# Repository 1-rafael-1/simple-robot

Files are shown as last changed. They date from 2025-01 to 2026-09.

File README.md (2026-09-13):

# simple-robot

A not-too-simple tracked robot with autonomous navigation and sensor-driven obstacle avoidance, written in Rust with Embassy. v2 reached the limits of its hardware platform; development continues in the follow-up [explorer-robot](https://github.com/1-rafael-1/explorer-robot) repository.

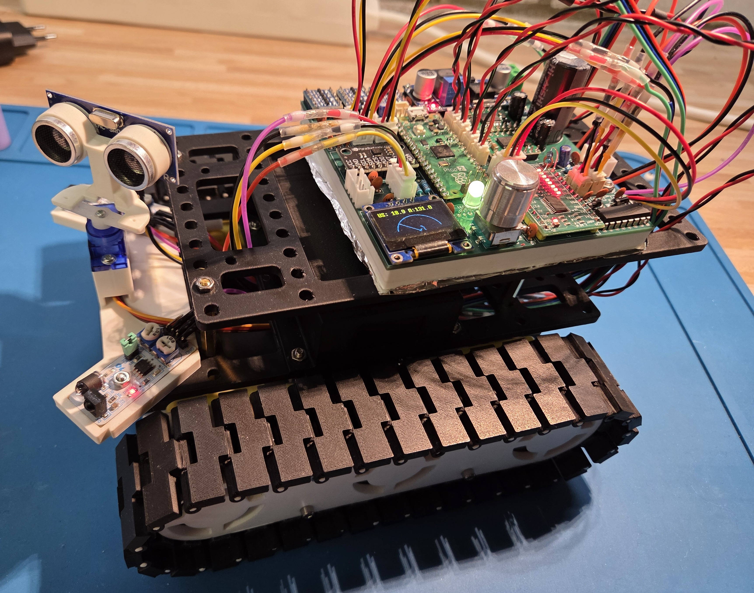
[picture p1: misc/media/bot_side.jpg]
Robot Side View

*Side view showing the robot's profile — the v2 iteration.*

## Project History

This started out as a hobby project for my 10-year-old son, who wanted me to build a robot for him. The thing started as a rather simple machine (v1) and then I got a little carried away. Check out the v1-robot navigating autonomously, download the demo video here: [Autonomous Operation](misc/media/autonomous-mode.mp4).

> Note: The initial version of this robot is preserved in the [`v1` tag](../../tree/v1). That version represents a simple but functional obstacle-avoiding robot using basic components. The v2 iteration described here is tagged [`v2`](../../tree/v2) and is now mothballed.

In v1, the robot could move autonomously by avoiding obstacles in a very simple way. That meant driving straight until an obstacle is detected, back up a little and then make a random turn. It was fun to watch and my son was happy with it.

v2 set out to be much more capable. The plan was to add spatial awareness through an IMU and a sweeping ultrasonic sensor, build more sophisticated autonomous navigation modes, and eventually integrate an AI camera module for follow-me and object-finding. Some of that worked out; some of it ran into hardware limits that couldn't be solved on this platform.

People have pointed out to me various things. The gist is that there are of course ready-made chassis solutions, ready-made RTOS for robotics and even probably complete systems available and that I am setting out to solve things that can be solved with much less effort by using existing things in code as well as hardware. This is all true and I do not dispute it. My motivation is different, though: I am not truly that much interested in having the actual robot, I have no use case at all for it, in fact. I just truly enjoy the process of building, figuring out how to do things, learning a ton of new stuff and it passes my rare spare time in a rewarding way.

## What v2 Achieved

The v2 firmware is a fully integrated platform built on Embassy async with a task-oriented architecture. A central orchestrator runs an event loop, dispatching sensor events to behavior handlers and UI updates. The drive subsystem uses a single-producer command queue with intents for distance drives, in-place rotations, and brake/coast settling — all with IMU-corrected feedback and ramp-down near targets. Mode-agnostic obstacle detection triggers emergency braking across all modes.

The robot carries a custom 4-layer PCB designed in KiCad, hand-soldered, with an RP2350 at 150 MHz. It drives four TT motors through two TB6612FNG motor drivers, reads four hall-effect encoders, and runs an ICM-20948 9-axis IMU with on-chip DMP sensor fusion. An HC-SR04 ultrasonic sensor on a servo performs 0–160° sweeps with a 30° cone correction algorithm, feeding a shared sweep buffer used by both the OLED's radar visualization and the autonomous navigation modes. Two front-facing IR sensors provide close-range collision detection, and a PCA9555 I2C port expander handles motor direction/standby pins and additional inputs. An RGB LED indicates battery state and obstacle alerts.

The UI is driven by an EC11 rotary encoder with push button and an SSD1306 OLED display. A menu system exposes hardware tests (motors, encoders, IMU, ultrasonic sweep, drive accuracy), calibration routines (motor speed, IMU, distance factor), and autonomous mode selection. Calibration data persists to flash storage.

Two autonomous modes are implemented:
- **Coast-and-avoid** — drives forward until an obstacle is detected, backs up, and turns a random angle. Simple but reliable.
- **Attempt straight line** — the user sets a target distance (100–1000 cm); the robot sweeps the ultrasonic sensor, performs gap analysis with drift correction, and navigates leg-by-leg toward the goal while avoiding obstacles.

Three side-quest crates were published along the way: [`hcsr04_async`](https://crates.io/crates/hcsr04_async) (async HC-SR04 driver), [`moving_median`](https://crates.io/crates/moving_median) (moving median filter), and [`icm20948-rs`](https://crates.io/crates/icm20948-rs) (ICM-20948 driver with DMP support).

## Why v2 Ends Here

The robot works, but it cannot reach the spatial awareness and navigation precision the original vision demanded. Several hard limits converge:

**Spatial awareness is the primary bottleneck.** The HC-SR04 ultrasonic sensor, even with servo sweeping and cone correction, is fundamentally imprecise. Its 30° detection cone could have been overcome algorithmically, but it produces false readings far too easily — a carpet, a floor tile seam, or a slightly textured surface registers as an obstacle. That makes reliable navigation impossible. The front-facing IR sensors work but have very short range and would require redesigning the sensor array holder to be truly useful. There is no downward-facing sensor to detect stairs or ledges.

**The board is out of pins.** The RP2350 on a Pico 2, even with a PCA9555 port expander, has every pin in use. There is no room to add a downward edge sensor, a better spatial sensor, or anything else. Some of those pins are spent on RC receiver inputs and a UART for an AI board that were never fully utilized, and on four motor encoders and two motor driver modules — overhead that a two-motor design would eliminate.

**Four TT motors reach a precision ceiling.** Two motors per track were necessary to move the Proto-Tank chassis, but that doubled the encoder and PWM pin count. The cheap hall-effect encoders and the inherent variability of TT motors mean no amount of calibration will deliver the positional accuracy needed for reliable dead-reckoning navigation.

**The I2C bus is shared** between the IMU, the OLED display, and the port expander. Motor direction changes go through the expander on that same bus. This never caused a hard failure in testing, but it is a fragile design with no headroom.

None of these are software problems. They are hardware constraints of a design that started from a simple tank chassis and grew organically. v2 went as far as it could on this platform.

## What's Next

Development continues in the follow-up **[explorer-robot](https://github.com/1-rafael-1/explorer-robot)** repository. I am not yet sure where this will go, but the plan is to build a more capable robot with better spatial awareness and navigation precision.

## Licensing Overview

This project uses multiple licenses depending on the component:

- **Firmware code** (`src/`, `build.rs`, `Cargo.toml`, etc.): Licensed under **MIT License** (see `LICENSE-MIT.md`)
- **3D-printed chassis designs** (`misc/chassis/`): Based on the Proto-Tank Chassis by fustyles, licensed under **CC BY-SA 4.0** (see attribution below)
- **Schematic and hardware design** (`misc/media/schematic_picture.png`): Licensed under **CC BY-SA 4.0** (see `LICENSE-CC-BY-SA-4.0.md`)
- **Documentation** (`docs/`, `README.md`): Licensed under **CC BY-SA 4.0**

Please review the individual license files and attribution sections for detailed information.

## Schematic

You can find the KiCad project here: [misc/KiCad/simple-robot](misc/KiCad/simple-robot). Some of the boards I used had no symbols & footprints and so I created them as I went. You can find them here: [misc/KiCad/symbols](misc/KiCad/symbols). The Pi Pico symbol I found online here: [ncarandini/KiCad-RP-Pico](https://github.com/ncarandini/KiCad-RP-Pico).

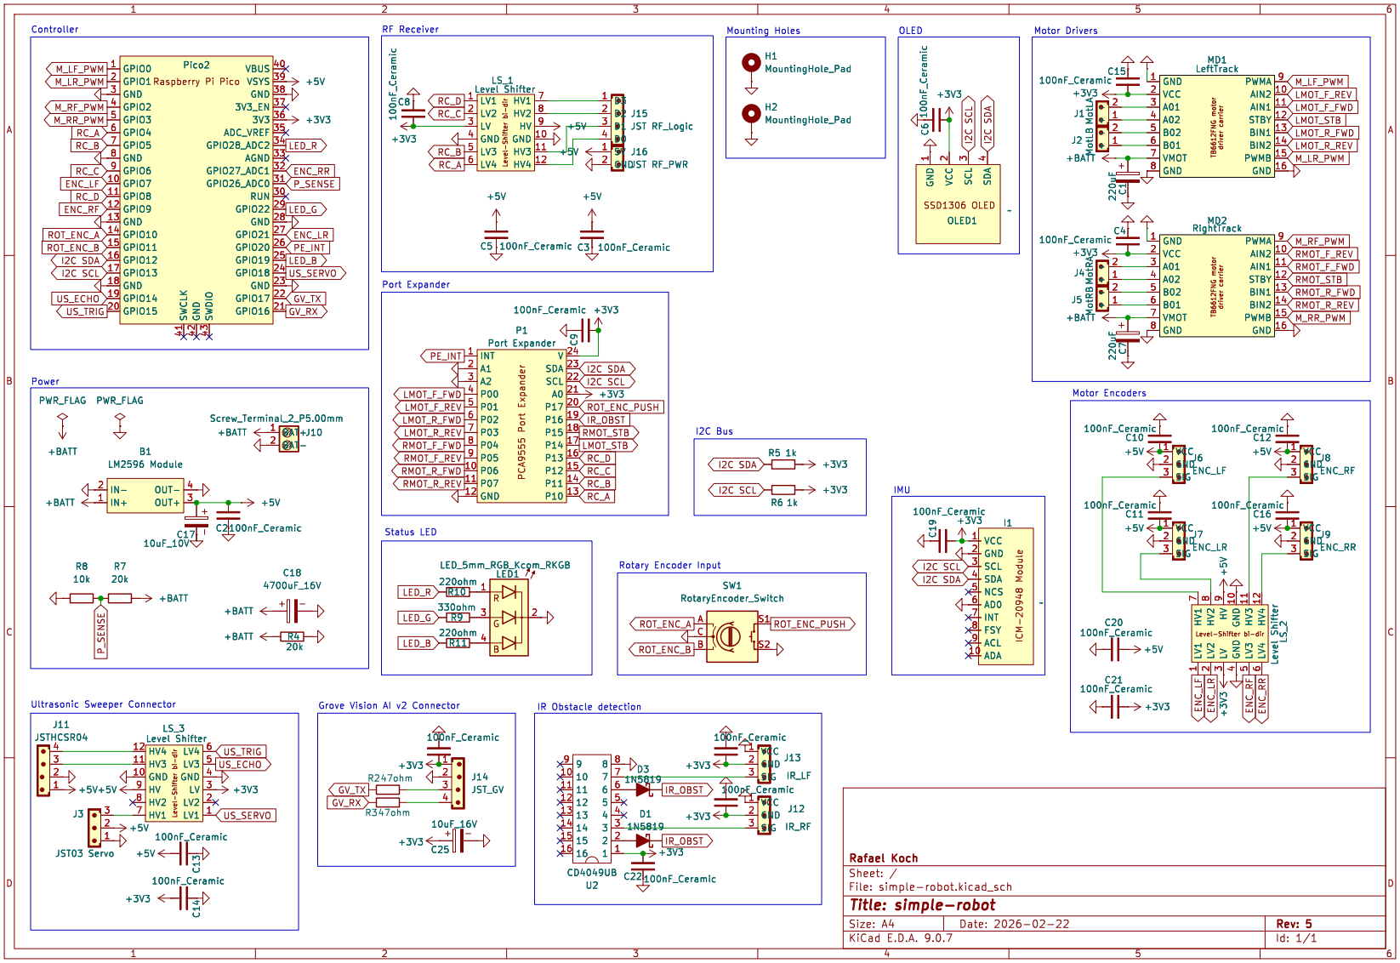
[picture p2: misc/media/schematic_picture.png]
robot-schematic

*The v2 schematic (current design)*

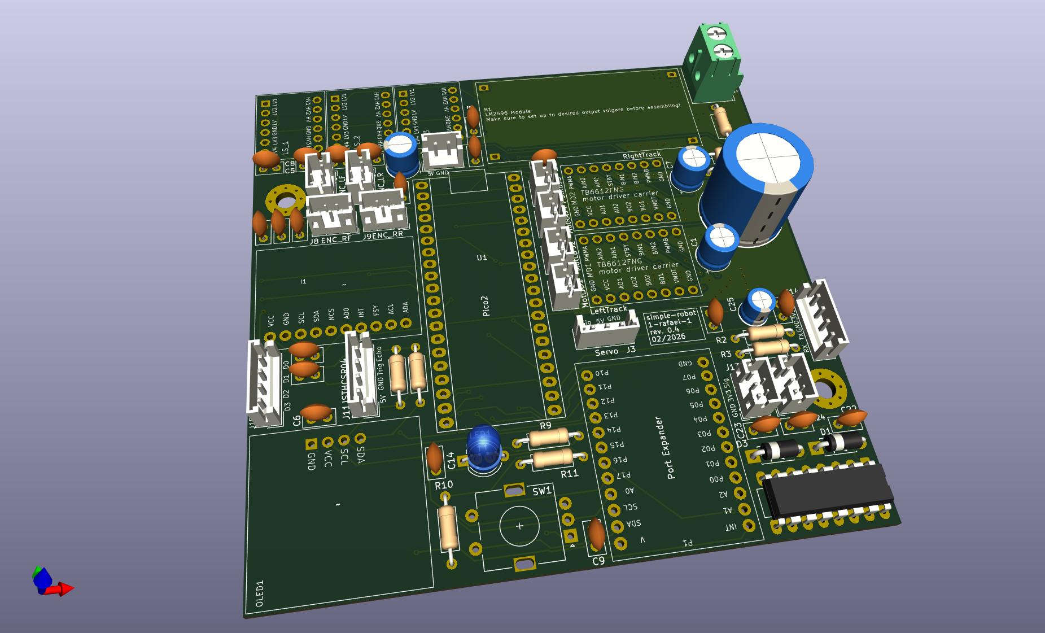
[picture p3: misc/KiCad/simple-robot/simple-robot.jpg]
robot-pcb

*The v2 PCB layout (current design)*

## 3D Printing

The robot chassis and various mounting components are designed to be 3D printed. I printed all parts in PLA and they worked quite okay so far. The 3D models are stored in the `misc/chassis` directory with both FreeCAD source files (.FCStd) and print-ready formats (.3mf, .stl).

For convenient printing with a Bambu Lab 3D printer, two Bambu Studio print projects are included:

- **print project.3mf** - Complete robot chassis assembly including the base frame, servo mount, HC-SR04 ultrasonic sensor mount, and IR sensor mounts
- **track pin print project.3mf** - Track pin components for securing and tensioning the robot's tracks (recently added)

The individual component files are also available if you prefer to customize your print settings:
- BaseFrame - edit.3mf/stl (main chassis frame)
- 9g servo mount.3mf (servo mounting bracket)
- hc-sr04 mount.3mf (ultrasonic sensor mount)
- IR Sensor mount.3mf (infrared sensor mounting)
- PCB mounting base.3mf (circuit board support)
- track pin.3mf (individual track pin component)

For more details on the chassis components, file formats, and assembly, see [misc/chassis/README.md](misc/chassis/README.md).

## Side quests that became necessary

Building the thing I found no async driver for the HC-SR04, so I had to make one myself:

- <https://github.com/1-rafael-1/hcsr04_async>
- Also on <https://crates.io/crates/hcsr04_async>.

This was fun :-)

Testing the ultrasonic sensor I found it gets even more unreliable when moving. So I searched for some moving median filtering solution, found none and made one myself:

- <https://github.com/1-rafael-1/moving_median>
- Also on <https://crates.io/crates/moving_median>

A little less fun.

I replaced the initial MPU9250/MPU6050 I never truly got to work with the ICM20948, a more modern 9-axis IMU from the same manufacturer (TDK InvenSense). The ICM20948 offers better performance and I created a driver for it:

- <https://github.com/1-rafael-1/ICM-20948-rs>
- Also on <https://crates.io/crates/icm20948-rs>

The driver supports async I2C operations and includes examples for RP2350. This was to a degree vibe-coded because that is truly out of my league, but it seems to work okay so far. I am sure there are many things that could be done better, but it is a start and I can now get good orientation data from the IMU, which is a big step forward for the project.

## The code

The code is written in Rust and makes heavy use of the Embassy framework. The architecture is task‑oriented, with a central orchestration loop handling events and routing them to behavior modules. Tasks stay resident and idle when not needed, which keeps the control flow predictable and makes it easy to evolve the system.

The drive subsystem is explicitly single‑producer/single‑executor: higher‑level modes build queues of drive steps, submit them to the drive queue executor, and await a single queue completion. Per‑step completion is internal to the executor, and interrupts remain available for preemption.

There are two modules, `system` and `task`. The `system` module contains rather general things like the event system and state. The `task` module contains the tasks that are run by the system.

### State Modules and Lock Order

The global state is split into domain-specific modules under `system/state/*` to reduce contention and keep hot paths lock-free where possible:

- `system/state/power.rs`
- `system/state/motion.rs`
- `system/state/perception.rs`
- `system/state/calibration.rs`

UI mode state lives in `task/ui/state.rs` (via `UI_STATE`) and is kept separate from the system state lock order.

When multiple state mutexes must be held at the same time, a uniform lock order is required to avoid deadlocks:

1. `POWER_STATE`
2. `CALIBRATION_STATE`
3. `PERCEPTION_STATE`
4. `MOTION_STATE`

The `main.rs` file is the entry point of the program but does nothing besides initializing some resources and then spawning all the tasks.

The firmware uses both cores of the RP2350 at the nominal 150 MHz clock speed: core0 runs the orchestrator, drive subsystem, sensors, and UI; core1 owns the I2C bus and runs the display, IMU, and port expander tasks. It uses a few percent of the flash space and about 20% of the RAM. The single I2C bus is shared between the IMU, the OLED display, and the port expander — this never caused issues in testing, but it is a tight design with no room for additional devices.

## Acknowledgments & Attribution

### Proto-Tank Chassis Design

The robot's tracked chassis is based on the [Proto-Tank](https://www.thingiverse.com/thing:972768) project, which is licensed under [Creative Commons Attribution 4.0 International](https://creativecommons.org/licenses/by/4.0/).

The Proto-Tank design has been modified and adapted for the simple-robot project to integrate custom motor mounts, PCB solutions, and sensor integration.

See [misc/chassis/ATTRIBUTION.md](misc/chassis/ATTRIBUTION.md) for full attribution details and license information.

## Disclaimer

I am a hobbyist, I have no formal electronics education and am still relatively new to the hobby (2.5 years now). I am also still as new to Rust and Embedded. By now I have a basic understanding of how things work and of what are higher level things in embedded. Enough for maker-level, far off from actual professional level. So expect imperfections.

I use AI when coding, which has proven to be an excellent teaching tool for learning a new language. It allows me to explore more advanced concepts than I could on my own, making self-teaching much easier than it was just a year or two ago. That being said: The code is my take on how to do this, actual professionals will find a thousand things one could do better. In case you find a thing that could be better: Happy to hear about it, get in touch! :-)

## Component Summary

The following is a summary of the components used in the v2 schematic (see [KiCad project](misc/KiCad/simple-robot)).

### Microcontroller

| Ref | Component | Notes |
|-----|---|---|
| U1 | Raspberry Pi Pico 2 (RP2350) | Main controller |

### Sensors

| Ref | Component | Notes |
|-----|---|---|
| I1 | ICM-20948 module | 9-axis IMU (accelerometer, gyroscope, magnetometer), I2C |
| J11 | HC-SR04 ultrasonic sensor | Connected via JST 4-pin, with servo sweeper |
| J12, J13 | IR obstacle detection sensors (×2) | Right-front and left-front |
| J14 | Grove Vision AI v2 | Camera/AI module, JST 4-pin |

### Motor Control

| Ref | Component | Notes |
|-----|---|---|
| MD1, MD2 | TB6612FNG motor driver carriers (×2) | Left track & right track |
| J6–J9 | Motor encoders (×4) | LF, LR, RF, RR via JST 3-pin |
| J1, J2, J4, J5 | DC motor connectors (×4) | JST 2-pin |

### Communication & IO Expansion

| Ref | Component | Notes |
|-----|---|---|
| P1 | PCA9555 I2C port expander | 16-bit GPIO expander |
| LS_1, LS_2, LS_3 | Bi-directional level shifters (×3) | 3.3V ↔ 5V |
| U2 | CD4049UB | Hex inverting buffer (DIP-16) |

### User Interface

| Ref | Component | Notes |
|-----|---|---|
| OLED1 | SSD1306 OLED display module | I2C |
| SW1 | Rotary encoder with push switch | User input |
| LED1 | 5mm RGB LED (common cathode) | Status indicator |
| — | RF receiver | Remote control, via JST 3-pin |

### Power

| Ref | Component | Notes |
|-----|---|---|
| B1 | LM2596 DC-DC buck converter module | Steps battery voltage down |
| J10 | Screw terminal (2-pin) | Battery input |
| D1, D3 | 1N5819 Schottky diodes (×2) | Power path protection |

### Passive Components

| Ref | Component | Notes |
|-----|---|---|
| C2–C16, C19–C24, C26 | 100nF ceramic capacitors (×20) | Decoupling |
| C18 | 4700µF 16V electrolytic | Bulk decoupling (motors) |
| C1, C7 | 220µF polarized (×2) | |
| C17 | 220µF 10V | |
| C25 | 10µF 16V | |
| R2, R3 | 47Ω (×2) | |
| R5, R6 | 1kΩ (×2) | |
| R8 | 10kΩ | |
| R4, R7 | 20kΩ (×2) | |
| R10, R11 | 220Ω (×2) | LED current limiting |
| R9 | 330Ω | LED current limiting |

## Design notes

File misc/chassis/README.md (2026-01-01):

# Robot Chassis & 3D Printed Components

This directory contains all the 3D models and designs for the simple-robot's chassis and mounting components.

## Directory Structure

### Original Proto-Tank Files
The `proto-tank/` subdirectory contains the original, unmodified files from the Proto-Tank project. These serve as the base design for the robot's tracked chassis.

### Modified & Custom Components
The root of this directory contains files that have been created or modified specifically for the simple-robot project:

- **BaseFrame - edit.3mf / .FCStd / .stl** - Modified base frame with filled bottom and cutouts for motor encoders
- **9g servo mount.3mf / .FCStd** - Custom mount for the 9g micro servo
- **PCB mounting base.3mf / .FCStd** - Custom mount for the simple-robot main PCB
- **hc-sr04 mount.3mf / .FCStd** - Mount for the HC-SR04 ultrasonic sensor
- **IR Sensor mount.3mf / .FCStd** - Mount for the IR obstacle detection sensors
- **track pin.3mf / .FCStd** - Track pin components for securing and tensioning tracks

## Print Projects

Two complete Bambu Studio print projects are included for convenient printing with Bambu Lab printers:

- **print project.3mf** - Complete robot chassis assembly including base frame, servo mount, sensor mounts, and PCB mount
- **track pin print project.3mf** - Track pin components for track assembly and tensioning

## File Formats

- **.3mf** - 3D print format with color and material information (recommended for Bambu Studio)
- **.FCStd** - FreeCAD source files for editing and customization
- **.stl** - Standard stereolithography format for universal 3D printer compatibility

## Assembly

For detailed assembly instructions and hardware requirements, refer to the original Proto-Tank project on Thingiverse: https://www.thingiverse.com/thing:972768. The images in the original project provide the same assembly instructions, you can find them in the images.

## Attribution & Licensing

See [ATTRIBUTION.md](ATTRIBUTION.md) for complete attribution information and licensing details regarding the Proto-Tank design and CC BY 4.0 requirements.

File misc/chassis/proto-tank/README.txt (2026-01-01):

ProtoTank by timmiclark on Thingiverse: https://www.thingiverse.com/thing:972768

Summary:
This thing has been replaced by this https://www.thingiverse.com/thing:2753227A bolt together modular tank style robotics platform!  I use this with my students. They get the base kit, then they customise.  I have run these with Arduino, Raspberry Pi and Intel Galileo, both in autonomous and controlled drone mode.  These tanks are very versatile and it is easy to create bolt on accessory holders as you need. I will post the accessories I have created here from time to time.  https://youtu.be/RU1G50hiegI

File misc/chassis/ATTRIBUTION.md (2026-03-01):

# Proto-Tank Attribution

**Original Project:** Proto-Tank  
**Original Creator:** [timmyclark](https://www.thingiverse.com/timmiclark)  
**Thingiverse URL:** https://www.thingiverse.com/thing:972768  
**License:** [Creative Commons Attribution 4.0 International](https://creativecommons.org/licenses/by/4.0/)

## About Proto-Tank

Proto-Tank is a tracked chassis design that serves as the foundation for the simple-robot's mobility platform. The design provides a robust and modular base for adding sensors, motors, and control electronics.

## Modifications

The Files of the original Proto-Tank design have been included in this repository unmodified for ease of access. Based on the original design, modified and additional files have been created to better integrate with the simple-robot project. These modifications include:

+ Added a modified base frame, with filled out bottom and cutouts to accommodate the motor encoders.
+ Added a sensor array mount for the ir sensors and the servo/hc-sr04 ultrasonic sensor.
+ Added a PCB mount for the simple-robot main board
+ Added a battery pack enclosure for the 18650 battery pack

The original files can be found in the `misc/chassis/proto-tank/` directory, while the modified files are located in the `misc/chassis/` directory.

## License Compliance

Per the Creative Commons Attribution 4.0 International license, the following conditions are met:
- **Attribution:** The original creator and Thingiverse project are credited
- **License Link:** A link to the CC BY 4.0 license is provided
- **Modifications Indicated:** The original design is included unmodified as well as additional modified parts are clearly indicated

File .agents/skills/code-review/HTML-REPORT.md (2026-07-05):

# HTML Report Format

The code review is rendered as a single self-contained HTML file in the OS temp dir. Tailwind comes from CDN; no other dependencies.

## Scaffold

```html
<!doctype html>
<html lang="en">
  <head>
    <meta charset="utf-8" />
    <meta name="viewport" content="width=device-width, initial-scale=1.0" />
    <title>Code review — {{branch}} · {{repo}}</title>
    <script src="https://cdn.tailwindcss.com"></script>
    <style>
      /* severity dots, filter tags, expandable detail panels */
      .sev-critical { background: #dc2626; }
      .sev-warning  { background: #d97706; }
      .sev-note     { background: #2563eb; }
      .finding-row  { cursor: pointer; }
      .detail-panel { display: none; }
      .detail-panel.open { display: table-row; }
    </style>
  </head>
  <body class="bg-stone-50 text-slate-900 font-sans">
    <main class="max-w-6xl mx-auto px-6 py-10 space-y-8">
      <header>...</header>
      <section id="summary">...</section>
      <section id="findings">...</section>
      <section id="top-issues">...</section>
    </main>
    <script>
      /* filter + expand/collapse logic */
    </script>
  </body>
</html>
```

## Header

Branch name, review scope (e.g. "5 commits ahead of origin/main + working tree changes"), timestamp, total finding count with a severity breakdown.

Compact, no introduction paragraph.

```html
<header class="space-y-1">
  <h1 class="text-2xl font-bold tracking-tight">Code Review</h1>
  <p class="text-sm text-slate-500">
    <span class="font-mono">{{branch}}</span> —
    {{N}} commits ahead of <span class="font-mono">origin/main</span> + working tree
  </p>
  <p class="text-sm text-slate-400">{{timestamp}}</p>
  <div class="flex gap-4 mt-3">
    <span class="flex items-center gap-1 text-sm font-medium">
      <span class="w-2.5 h-2.5 rounded-full sev-critical"></span> {{critical_count}} Critical
    </span>
    <span class="flex items-center gap-1 text-sm font-medium">
      <span class="w-2.5 h-2.5 rounded-full sev-warning"></span> {{warning_count}} Warning
    </span>
    <span class="flex items-center gap-1 text-sm font-medium">
      <span class="w-2.5 h-2.5 rounded-full sev-note"></span> {{note_count}} Note
    </span>
  </div>
</header>
```

## Summary Cards

One card per review dimension that had findings. Each card shows the dimension name and a mini bar chart (horizontal stacked bar of critical/warning/note counts). If a dimension was clean, show a green checkmark card.

```html
<section id="summary" class="grid grid-cols-2 md:grid-cols-3 lg:grid-cols-6 gap-3">
  <div class="rounded-lg border border-slate-200 bg-white p-4">
    <h3 class="text-xs font-semibold uppercase tracking-wider text-slate-500 mb-2">Safety</h3>
    <div class="flex h-2 rounded-full overflow-hidden bg-slate-100">

    </div>
    <div class="flex justify-between mt-2 text-xs text-slate-500">
      <span class="text-red-600 font-semibold">2</span>
      <span class="text-amber-600 font-semibold">3</span>
      <span class="text-blue-600 font-semibold">1</span>
    </div>
  </div>
  <!-- repeat per dimension -->
</section>
```

## Findings Table

Sortable (click column headers), filterable (severity toggle pills, category dropdown, file search input). Columns: File, Line, Sev, Category, Title (compact view).

```html
<section id="findings" class="space-y-4">
  <div class="flex flex-wrap gap-2 items-center">
    <!-- filter pills -->
    <button class="px-3 py-1 text-xs font-medium rounded-full border sev-critical text-white">Critical</button>
    <button class="px-3 py-1 text-xs font-medium rounded-full border border-red-300 text-red-700 bg-white">Warning</button>
    <button class="px-3 py-1 text-xs font-medium rounded-full border border-blue-300 text-blue-700 bg-white">Note</button>
    <select class="ml-auto text-sm border border-slate-300 rounded px-2 py-1">...</select>
    <input type="text" placeholder="Filter by file…" class="text-sm border border-slate-300 rounded px-2 py-1 w-48" />
  </div>

  <div class="overflow-x-auto rounded-lg border border-slate-200 bg-white">
    <table class="w-full text-sm">
      <thead>
        <tr class="bg-slate-50 text-left text-xs uppercase tracking-wider text-slate-500">
          <th class="px-4 py-3 cursor-pointer select-none">File ▾</th>
          <th class="px-4 py-3 cursor-pointer select-none w-16">Line</th>
          <th class="px-4 py-3 cursor-pointer select-none w-20">Sev</th>
          <th class="px-4 py-3 cursor-pointer select-none w-32">Category</th>
          <th class="px-4 py-3">Title</th>
        </tr>
      </thead>
      <tbody>
        <tr class="finding-row border-t border-slate-100 hover:bg-slate-50" onclick="this.nextElementSibling.classList.toggle('open')">
          <td class="px-4 py-2.5 font-mono text-xs">{{file}}</td>
          <td class="px-4 py-2.5 text-xs text-slate-500">{{line}}</td>
          <td class="px-4 py-2.5"><span class="inline-block w-2 h-2 rounded-full sev-{{severity}}"></span> {{severity}}</td>
          <td class="px-4 py-2.5 text-xs text-slate-500">{{category}}</td>
          <td class="px-4 py-2.5 font-medium">{{title}}</td>
        </tr>
        <tr class="detail-panel border-t border-slate-100 bg-slate-50">
          <td colspan="5" class="px-6 py-4">
            <p class="text-sm text-slate-700 whitespace-pre-line">{{detail}}</p>
            <pre class="mt-2 bg-slate-900 text-slate-100 text-xs p-3 rounded overflow-x-auto"><code>{{snippet}}</code></pre>
          </td>
        </tr>
      </tbody>
    </table>
  </div>
</section>
```

### Filter behaviour

Vanilla JS, no framework. Clicking a severity pill toggles that severity on/off. The select filters by category. The text input filters by file path substring. All filters combine with AND. If no rows match, show "No findings match — try adjusting filters."

### Sort behaviour

Click a column header to sort ascending; click again for descending. An arrow indicator shows current sort direction. Default sort: severity (critical first, then warning, then note), then file path alphabetical.

### Expand behaviour

Click a row to toggle its detail panel. Detail shows the full explanation and a syntax-highlighted code snippet (using `<pre><code>` with manual token colouring — no highlight.js CDN, keep it light).

## Top Issues

The 3 most actionable findings. Each gets a bordered card:

```html
<section id="top-issues" class="space-y-4">
  <h2 class="text-lg font-semibold">Top Issues</h2>
  {{#each top_issues}}
  <div class="rounded-lg border border-slate-200 bg-white p-5">
    <div class="flex items-start gap-3">
      <span class="mt-0.5 sev-{{severity}} text-white text-xs font-bold px-2 py-0.5 rounded">{{severity}}</span>
      <div>
        <h3 class="font-semibold">{{title}}</h3>
        <p class="text-sm text-slate-500 mt-1"><span class="font-mono">{{file}}:{{line}}</span></p>
        <p class="text-sm text-slate-700 mt-2">{{summary}}</p>
        <div class="mt-3 bg-slate-50 rounded p-3 text-sm">
          <span class="font-semibold text-slate-600">Fix:</span> {{fix_suggestion}}
        </div>
      </div>
    </div>
  </div>
  {{/each}}
</section>
```

## Style guidance

- Editorial, not dashboard. Generous whitespace. Stone/slate palette.
- One accent per severity (red/amber/blue). No other colours.
- `font-mono` for file paths, line numbers, code snippets.
- No icons, no emojis in the report. Let the data speak.
- The only script is the Tailwind CDN plus the ~30 lines of filter/sort/expand JS. No framework, no runtime.
- Keep the detail panel code snippets to ≤20 lines — just enough context to see the issue. Reference line numbers.
- Scroll the table vertically if it exceeds viewport height; keep the header fixed.

## Tone

Plain English, direct. No hedging ("seems like", "maybe", "perhaps", "could be worth considering"). Each finding states what's wrong and what to do.

**Good titles:**
- "Unsafety comment missing for PAC register write"
- "Lock acquired across .await point in distance control"
- "`unwrap()` on encoder read — silent panic path"
- "New term 'obstacle fusion' missing from glossary"

**Bad titles:**
- "Potential issue with unsafe code"
- "Documentation could be improved"
- "Might want to consider adding a glossary entry"

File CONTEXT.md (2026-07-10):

# Domain Glossary

Shared vocabulary for the simple-robot project. Use these terms when discussing architecture, design, or implementation.

## Hardware

**Microcontroller**
The Raspberry Pi Pico 2 (RP2350), the main processor running the firmware. One core used at 150 MHz.

**IMU** (Inertial Measurement Unit)
The ICM-20948 9-axis sensor (accelerometer, gyroscope, magnetometer). Provides orientation data for navigation and stabilization. Currently the magnetometer is unreliable (motor/wire interference), so effectively 6-axis in practice.

**Ultrasonic Sensor**
The HC-SR04 distance sensor mounted on a servo. Provides distance readings (cm) at varying angles. Used for obstacle detection and spatial awareness.

**IR Sensors** (Infrared)
Two IR obstacle detection sensors (left-front, right-front). Edge-triggered: report obstacle present/absent. Less precise than ultrasonic but reliable at close range.

**Encoders**
Four motor encoders (left-front, left-rear, right-front, right-rear). Report pulse counts per motor revolution. Used for speed measurement, distance tracking, and drift compensation.

**Motor Driver**
Two TB6612FNG motor driver carriers (one per track). Controlled via PWM for speed and direction.

**OLED**
SSD1306 I2C display (128×64 pixels). Primary user interface for menus, sensor readouts, and status. The top 16 px show text (4 lines × 20 characters); the bottom 48 px render a radar sweep visualization showing obstacle positions from the sweep buffer.

**Rotary Encoder**
EC11 rotary encoder with push button. The main user input for menu navigation and selection. A/B quadrature signals on Pico GPIO 22/23 via PIO; push button on port expander Port 1 bit 7.

**RC Receiver**
Remote control receiver with 4 buttons (A/B/C/D). Used for teleoperation and mode switching.

**LED** (RGB LED)
Status indicator — shows battery level and obstacle detection state via color.

**Port Expander**
PCA9555 I2C GPIO expander. Outputs: motor direction pins (Port 0, 8 bits) and motor driver chip enables (Port 1, bits 4-5). Inputs: RC receiver buttons A-D (Port 1, bits 0-3), IR obstacle detect (Port 1, bit 6), rotary encoder push button (Port 1, bit 7). The rotary encoder's A/B quadrature signals go directly to Pico GPIO 22/23 (PIO); the servo uses Pio on a separate Pico pin.

**Battery**
LiPo battery pack, stepped down via LM2596 buck converter. Voltage monitoring provides charge level (0–100%).

**Vision Module**
Grove Vision AI v2 camera module (future use). Intended for follow-me and object-finding modes.

## Driving

**Track**
One side of the robot's drivetrain (left or right). Each track has two motors driving a continuous belt.

**Coast**
Freewheel — motors are unpowered, the robot rolls to a stop. Slower deceleration than braking.

**Brake**
Active electrical braking — motors are shorted or driven in opposition for rapid stop.

**Drive Distance**
A `DriveAction` that commands the robot to travel a specified distance (straight or curved arc) using encoder feedback with optional IMU correction. Completes when the target distance is reached or an interrupt preempts it.

**Rotate Exact**
A `DriveAction` that commands an in-place rotation to a target angle using IMU feedback. Completes when the angle is reached within tolerance.

**Drift Compensation**
Encoder-based correction that equalises left/right track speeds to prevent veering. Currently handled by higher-level intents (distance, rotation) via IMU heading correction and encoder feedback — the inline per-command path was removed from `Differential` (now a passthrough). The pure math lives in `distance.rs` as helper functions.

**Ramp-Down**
Progressive speed reduction as a distance or rotation command approaches its target. Prevents overshoot.

**Sweep**
A full 0–160° pass of the ultrasonic sensor on its servo, producing one distance reading per 1° of angle. Obstacle positions in the sweep buffer are corrected for the sensor's 30° detection cone (see Sweep Correction). Used to build a spatial picture for gap analysis.
_Avoid_: Scan, radar pass

**Sweep Correction**
Algorithm applied to each contiguous obstacle run in a sweep that compensates for the ultrasonic sensor's 30° detection cone. Subtracts 15° from each edge of the run and splits runs into separate obstacles when a >40% distance jump is detected. Corrected positions overwrite the raw readings in the sweep buffer.
_Avoid_: Cone compensation, de-widening

**Obstacle Run**
A contiguous sequence of Some(distance) readings within a sweep, bounded by Timeout/Error readings or sweep boundaries (0° or 160°). Each run is independently corrected by Sweep Correction.
_Avoid_: Detection block, contiguous hit

**Distance Discontinuity**
A >40% jump in reported distance between consecutive angles within an obstacle run. Signals that two physically separate obstacles at different distances are merging into one run due to the 30° cone overlap. Causes the run to be split into sub-runs before correction.
_Avoid_: Range jump, depth break

**Sweep Buffer**
A shared `[Option<u16>; 161]` array (`SWEEP_BUFFER`) indexed by servo angle (0–160°). Each entry holds a distance reading in millimeters (`Some`) or a timeout/error marker (`None`). Written by the ultrasonic task during sweeps after cone correction; read by gap analysis and the display for rendering.
_Avoid_: Radar buffer, scan buffer

**ObstaclePoint**
A data struct carrying a single corrected obstacle detection: `angle_deg: f32` (servo angle, 0–160°) and `distance_cm: f64` (distance in centimeters). Extracted from the sweep buffer by `sweep_buffer_points()` for consumers that need point-level data (e.g., display rendering).
_Avoid_: SweepPoint, detection point

**SweepPoints**
A fixed-capacity list of `ObstaclePoint` values (max 32). Returned by `sweep_buffer_points()` — the canonical conversion from the raw sweep buffer to consumer-friendly obstacle coordinates. Capacity is bounded because a 161° sweep produces at most ~54 corrected obstacles (3° minimum width), and 32 points saturate a 128×64 display.
_Avoid_: Point list, obstacle list

**Gap**
A contiguous angular arc within a corrected sweep where the ultrasonic sensor reads clear (no obstacle within 15 cm). A valid gap has at least 30 cm lateral width at its constriction depth, is flanked by obstacles on both sides, and lies within ±90° of the robot's forward center. The robot drives through a gap by rotating to its midpoint angle and driving straight.
_Avoid_: Opening, corridor, path

**Constriction Depth**
The minimum distance reading across the angles that make up a gap. Determines how far the robot can safely travel through that gap before it must re-sweep.
_Avoid_: Minimum range, bottleneck distance

**Leg**
One rotation-then-straight-drive maneuver through a selected gap. A leg's length is the constriction depth (minus 10 cm safety margin), or the remaining target distance if shorter. The robot's accumulated drift and total forward progress are updated after each leg.
_Avoid_: Step, segment, hop

**Accumulated Drift**
The signed sum of all deviation angles taken so far during an Attempt Straight Line run. Positive = right, negative = left. The correction target for the next leg is `-drift`, so the robot strives to return toward the ideal unobstructed course.
_Avoid_: Heading error, offset sum

**Correction Angle**
The ideal gap midpoint angle that would cancel the accumulated drift (= `-drift`). The gap closest to this angle is preferred when choosing the next leg.
_Avoid_: Recovery angle, compensation heading

## Modes

**RC Mode** (Remote Control)
Direct teleoperation via remote control buttons. The operator steers.

**Autonomous Mode**
The robot drives itself. Two variants: coast-and-avoid and attempt-straight-line.

**Coast-and-Avoid**
An autonomous mode: drive forward until an obstacle is detected (via IR or ultrasonic), then back up and turn a random angle before resuming. Has two phases:
- **Forward phase**: driving forward at constant speed, obstacle detection is armed.
- **Avoidance phase**: backing up and turning after an obstacle interrupt.

**Attempt Straight Line**
An autonomous mode: travel toward a user-set target distance (100–1000 cm) while avoiding obstacles to approximate the endpoint an unobstructed straight line would have reached. The robot sweeps the ultrasonic sensor 0–160°, finds gaps through obstacles, drives a leg toward the best gap, and repeats until the target distance is reached or no forward progress is possible. Accumulated drift is tracked across legs so later legs correct past deviations.

**Test Mode**
Interactive hardware tests accessible from the menu: motor test, encoder test, IMU display (6-axis and 9-axis), ultrasonic sweep, IR+ultrasonic live display, turn accuracy test, straight drive test, arc drive test.

**Calibration**
Procedures that measure and store correction factors: motor speed calibration, IMU calibration (magnetometer), distance factor calibration. Results are persisted to flash storage.

## Architecture

**Orchestrator**
The central `orchestrate` task. Runs a single event loop: waits for events from the system event channel and dispatches them to behavior handlers or UI handlers. Pure routing — no domain logic.

**Event System**
A multi-producer, single-consumer channel (`Events` enum, capacity 64). Sensor tasks and input tasks raise events; the orchestrator consumes them. The seam between producers and consumers.

**State Modules**
Four domain-specific state modules under `system/state/`, each with its own `Mutex`:
1. **Power** — battery level and voltage.
2. **Calibration** — calibration data load status, flags, and the distance calibration factor.
3. **Perception** — obstacle detection state (IR, ultrasonic, combined) and ultrasonic readings. Deepened: all access goes through accessor functions; internal atomics provide lock-free reads.
4. **Motion** — track speed state, also exposed via lock-free atomics for the IMU hot path.

**Lock Order**
When multiple state mutexes must be held: Power → Calibration → Perception → Motion. Prevents deadlocks.

**Drive Subsystem**
The `drive` module tree. Owns the drive task, command queue, interrupt signal, control algorithms (rotation, distance, brake/coast, differential), sensor feedback channels, and calibration procedures. Commands flow through a thin `dispatch` that routes to control modules. Control modules own sensor setup internally; teardown is declared via `IntentTeardown` descriptors and executed by the dispatch on completion or interrupt. Exposes two public entry points: `send_drive_command` and `send_drive_interrupt`.

**Drive Queue**
A builder (`DriveQueueBuilder`) that accumulates `DriveCommand` steps and submits them for sequential execution. A single `drive_queue_executor` task runs one queue at a time and emits a single queue-level completion.

**Intent**
A state machine that owns a specific motion behaviour — rotation, distance drive, brake/coast settle, or idle. Each intent is an `ActiveIntent` variant carrying its controller state, completion flag, and lifecycle descriptors. Commands that complete instantly (e.g. `Differential`) are not intents; they are fire-and-forget.

**IntentTeardown**
An enum declaring what sensor streams must be stopped when an intent completes or is interrupted. Each `ActiveIntent` variant returns its teardown descriptor via `teardown()`; the `dispatch` executes it. This keeps the dispatch thin — it knows to stop sensors but not which specific sensors each intent required. Sensor setup is owned by each intent's async `init()` function. See [ADR-0004](docs/adr/0004-intent-setup-removal.md).

**Dispatch**
The `dispatch` module — the thin seam between the drive command queue and the control modules. Routes incoming `DriveCommand` envelopes, handles standby wake-up, and executes `IntentTeardown` descriptors on completion or interrupt. Owns no per-intent knowledge.

**Behavior Handlers**
Functions under `task/behavior/` that react to specific events. Domain logic lives here — obstacle fusion, sensor forwarding, battery updates. Called by the orchestrator.

**UI Subsystem**
The `task/ui/` module tree. Owns the display rendering, menu navigation, and UI state (`UiMode` enum). Receives rotary encoder events from the orchestrator.

**Sensor Tasks**
Embassy tasks that interface with hardware sensors (`task/sensors/`): IMU read loop, encoder read loop, IR obstacle polling, ultrasonic sweep/servo control. Measurement data flows point-to-point via direct channels into the drive subsystem or perception state (bypassing the event bus). Semantic events (obstacle detection, button presses) still flow through the system event channel via `raise_event`.

**IO Modules**
Hardware abstraction tasks under `task/io/`: display driver, flash storage (calibration persistence), port expander driver. Use channel-based command APIs.

**Perception**
The deepened state module that owns obstacle detection. Obsolete: direct `PERCEPTION_STATE` field access. Current: accessor functions for lock-free boolean reads (`is_obstacle_detected`, `is_ir_obstacle_detected`, `is_ultrasonic_obstacle_detected`) and mutex-guarded reading/angle storage (`set_ultrasonic_reading`, a pure data store). Obstacle classification flows through the event bus: sensor tasks raise `Events::ObstacleDetected`, the behavior handler calls `set_ir_obstacle` / `set_ultrasonic_obstacle` to update atomics. See [ADR-0003](docs/adr/0003-perception-event-bus.md).

**Obstacle Threshold**
The distance cutoff (default 20 cm, matching the ultrasonic sensor task's `ULTRASONIC_OBSTACLE_THRESHOLD_CM`) used by the ultrasonic sensor task to classify readings as obstacles. Reading distance ≤ threshold → `Events::ObstacleDetected` raised on the event bus. The perception module no longer owns threshold-based classification (see [ADR-0003](docs/adr/0003-perception-event-bus.md)).

**ObstacleSource**
An enum (`Ir` | `Ultrasonic`) carried by `Events::ObstacleDetected` that identifies which sensor triggered the detection. Used by the obstacle behavior handler to route updates to the correct perception atomic.

**InterruptKind**
An enum (`EmergencyBrake`, `Stop`, `CancelCurrent`) that specifies how the drive subsystem preempts the active intent. See also [`Dispatch`](#dispatch).

**EmergencyBrake**
An `InterruptKind::EmergencyBrake` interrupt sent to the drive subsystem when a combined obstacle is detected. Causes immediate active motor braking, cancels the active intent (if any), bumps the command epoch, and drains queued commands. Mode-agnostic since [ADR-0005](docs/adr/0005-agnostic-obstacle-handling.md) — dispatched unconditionally on any obstacle detection across all modes.

**Change Detected**
An enum (`ChangeDetected`) returned by perception setters: `NoChange`, `ChangedToDetected`, `ChangedToCleared`. Lets callers react to obstacle state transitions without re-reading the combined flag.

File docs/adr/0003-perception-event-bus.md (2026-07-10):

# Ultrasonic perception — event-bus-only path and pure data store

The ultrasonic sensor task wrote obstacle state through two parallel paths: directly via `set_ultrasonic_reading` (which updated atomics) and indirectly via `Events::ObstacleDetected` → `handle_obstacle_detected` → `set_ultrasonic_obstacle` (which updated the same atomics). This dual-write path created a race condition and made the `ChangeDetected` return from `set_ultrasonic_obstacle` unreliable. Additionally, `set_ultrasonic_reading` acquired the perception mutex twice, creating a TOCTOU window between threshold read and reading storage.

## Considered options

**Keep the dual-write path and fix TOCTOU separately.** Would have merged the two mutex acquires in `set_ultrasonic_reading` without addressing the race with the event-bus path. **Rejected** — the dual-write race remained, just with a narrower TOCTOU window.

**Remove the event bus path, make `set_ultrasonic_reading` the sole atomic writer.** Would have made ultrasonic asymmetric with IR (which still uses the event bus). **Rejected** — asymmetry is its own friction; both obstacle sensors should use the same communication pattern.

**Event bus only, `set_ultrasonic_reading` becomes pure data store.** The ultrasonic task classifies obstacles locally (as it already does) and raises `Events::ObstacleDetected`. `handle_obstacle_detected` remains the single writer of both `IR_DETECTED` and `ULTRASONIC_DETECTED` atomics. `set_ultrasonic_reading` stores only the reading + angle in the mutex — no atomics, no threshold read. **Chosen** — symmetric with IR, one writer per atomic, TOCTOU vanishes naturally.

## Consequences

- `set_ultrasonic_reading` loses its threshold-aware obstacle classification and atomic updates. It becomes a pure data store with a single lock scope.
- `set_ultrasonic_obstacle` remains the sole writer of `ULTRASONIC_DETECTED`, called only from the event-bus path.
- Both IR and ultrasonic obstacle state follow the same flow: sensor task → event bus → behavior handler → perception atomics.
- The dual-write race is eliminated.
- The TOCTOU window is eliminated.

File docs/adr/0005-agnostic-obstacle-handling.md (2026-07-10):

# Mode-agnostic obstacle handling — unconditional EmergencyBrake

The obstacle behavior handler (`handle_obstacle_detected`) directly checked `coast_obstacle_avoid::is_active()`, `coast_obstacle_avoid::is_forward_phase()`, and `attempt_straight_line::is_active()` to decide whether to send an `EmergencyBrake` interrupt. This coupled the handler to knowledge of which autonomous modes existed and what phases they were in. Adding a third autonomous mode would require editing the obstacle handler.

## Considered options

**Mode self-filtering via atomics.** Each autonomous mode task reads perception atomics in its own control loop and self-interrupts. **Rejected** — adds worst-case 20ms latency (control tick period) vs. the current direct `Signal` wake. Obstacle avoidance needs immediate braking.

**Registration mechanism.** Modes register a wake signal with the handler. **Rejected** — one adapter means a hypothetical seam. Adds complexity without a second consumer.

**Unconditional EmergencyBrake.** `handle_obstacle_detected` sends an `EmergencyBrake` interrupt on any combined obstacle detection, regardless of mode. `handle_interrupt` in dispatch brakes motors, bumps the command epoch, and drains queued commands — even when no intent is active. This is the intended safety behaviour: IR sensors are armed in all modes (RC, autonomous, testing), and obstacle braking is a system-wide safety invariant. The epoch bump + queue drain are side-effects that always apply; non-autonomous callers should not queue commands they cannot afford to lose. **Chosen** — simplest change, preserves immediate wake, mode-agnostic handler, zero coupling, consistent safety response across all modes.

## Consequences

- `handle_obstacle_detected` loses all imports of `coast_obstacle_avoid` and `attempt_straight_line`.
- The handler's logic reduces to: update perception atomics → update LED indicator → send unconditional `EmergencyBrake` if combined obstacle detected.
- New autonomous modes require no changes to the obstacle handler.
- IR obstacle sensors are armed in all modes (RC, autonomous, testing). Obstacle braking is a system-wide safety invariant: any obstacle detection immediately brakes motors, bumps the command epoch, and drains queued drive commands.
- Callers that queue drive commands during RC mode or testing must expect them to be dropped on obstacle detection.

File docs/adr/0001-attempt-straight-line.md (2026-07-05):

# Attempt Straight Line — buffered sweep, gap analysis, and drift correction

The robot needed an autonomous mode that travels toward a user-set target distance while avoiding obstacles via sensor-guided steering. The design combines a buffered ultrasonic sweep with gap-analysis geometry and accumulated drift correction to approximate the endpoint an unobstructed straight line would have reached.

## Considered Options

**Sweep data collection**: streaming each reading through `perception::set_ultrasonic_reading` (loose coupling, reuses existing pipeline) vs. buffering a full 0–160° pass into a shared `Mutex<[Option<u16>; 161]>` and raising a lean `UltrasonicSweepCompleted` event. **Chose buffering** — gap analysis needs consistent, synchronous access to the whole angular picture, and a 2093-byte buffer on the event channel would be rejected by Clippy. The mm representation (`u16`) is dense enough for a 161-entry heapless buffer while staying memory-friendly.

**Gap selection priority**: minimize divergence from current heading vs. minimize accumulated drift. **Chose drift-first** — the mode's purpose is to reach the user's target waypoint, so correcting past deviations matters more than staying on the instantaneous heading. Ties break toward 0° (straight ahead).

**Speed-boundary obstacle gating**: a system-wide sensor gate vs. gating in the drive mode task itself. **Chose in-task gating** — the mode only arms obstacle detection during drive legs (via `start_ultrasonic_fixed` with `obstacle_detect: true`), and leaves it disarmed during sweeps where the robot is stationary. Deferred system-wide motion-state gating until it is needed across multiple modes.

**Travel distance entry**: embedding range/step constants in the UI controller vs. exposing them from the drive mode module. **Chose encapsulation in the drive mode module** — a new `UiMode` variant handles the UX, but constants (100–1000 cm, 10cm steps, 300cm preset) live in the mode's module, surfaced through accessors. The confirmed distance passes to the mode task via `AutonomousCommand::AttemptStraightLine { target_distance_cm: u16 }`, flowing through the existing autonomous mode controller channel.

## Consequences

- The event system gains `UltrasonicSweepCompleted`, routed by the orchestrator to the mode's handler.
- The sweep task gains a `StartBufferedSweep` command that does one 0–160° pass into the shared buffer.
- Gap analysis is stateless: walk the buffer once, classify clear/obstacle/unknown per angle, extract contiguous arcs, compute constriction depth and width, filter to valid gaps (≥30 cm width, flanked by obstacles ≤15 cm, within ±90° of center), then score by drift correction.
- Partial progress on emergency-braked legs is tracked via `cancellation_telemetry()` from the intent subsystem, so the mode always knows true remaining distance.
- Future spatial-awareness modes (e.g., full room scan, follow-me) can reuse the buffered sweep and gap-analysis primitives.

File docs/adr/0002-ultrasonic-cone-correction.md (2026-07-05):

# Ultrasonic cone correction — in-place buffer mutation with heuristic obstacle splitting

The HC-SR04 ultrasonic sensor's 30° detection cone inflates every obstacle's apparent width by 30° in the sweep buffer, making obstacles appear wider than they are and degrading gap analysis. We apply a geometry-based correction that shrinks each contiguous obstacle run by 15° on each edge, mutating `SWEEP_BUFFER` in-place so all consumers (display, gap analysis) see corrected data with no extra steps.

## Considered Options

**Raw + corrected dual buffer vs. in-place mutation.** Keeping raw data in a separate buffer would preserve it for debugging but doubles the 322-byte footprint and forces every consumer to know which buffer to read. **Chose in-place mutation** — the raw data has no consumer that needs it after correction, and a single buffer simplifies the display and gap-analysis paths.

**Full deconvolution vs. heuristic splitting.** A full deconvolution could infer each obstacle's true angular profile from the cone's overlap pattern, but requires assumptions about obstacle geometry (flat walls, circular posts) that don't generalise. **Chose heuristic splitting** — a >40% distance jump within a contiguous run signals a separate obstacle, and each sub-run is independently edge-corrected. Simple, handles the common case (two obstacles at different distances), and degrades gracefully for angled walls.

**On-the-fly vs. post-sweep correction.** Correcting each run as it ends during the sweep enables real-time corrected display updates mid-sweep and keeps the same code path for continuous and buffered sweeps. **Chose on-the-fly** — the sensor task tracks run boundaries and calls correction at each `Some → None` transition, so the buffer is always fully corrected.

## Consequences

- The display path consolidates from two `ShowSweep` callers with separate point-accumulation logic to a single `ShowSweepFromBuffer` variant that renders corrected points from the buffer. `PointsBuffer`, direction tracking, and point retention logic are removed from the display task.
- Gap analysis (`attempt_straight_line`) receives corrected obstacle widths without any change — it already reads from `SWEEP_BUFFER`.
- Obstacle runs touching the sweep boundary (0° or 160°) receive one-sided correction only, so boundary obstacles are treated as wider than they may actually be. This is conservative for gap analysis.
- Minimum obstacle width of 3° (corrected) prevents thin objects like chair legs from collapsing to points while keeping the correction honest for genuinely narrow obstacles.
- Corrected obstacle interiors are filled with the minimum distance in the run (not left as `None` between edges). This is conservative for gap analysis — the constriction depth may be slightly underestimated, but it prevents false gaps from appearing inside corrected obstacles.
- A dedicated `ultrasonic_correction` module keeps the correction logic testable in isolation with no hardware or async dependencies.

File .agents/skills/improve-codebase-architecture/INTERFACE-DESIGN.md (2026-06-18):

# Interface Design

When the user wants to explore alternative interfaces for a chosen deepening candidate, use this parallel sub-agent pattern. Based on "Design It Twice" (Ousterhout) — your first idea is unlikely to be the best.

Uses the vocabulary in [LANGUAGE.md](LANGUAGE.md) — **module**, **interface**, **seam**, **adapter**, **leverage**.

## Process

### 1. Frame the problem space

Before spawning sub-agents, write a user-facing explanation of the problem space for the chosen candidate:

- The constraints any new interface would need to satisfy
- The dependencies it would rely on, and which category they fall into (see [DEEPENING.md](DEEPENING.md))
- A rough illustrative code sketch to ground the constraints — not a proposal, just a way to make the constraints concrete

Show this to the user, then immediately proceed to Step 2. The user reads and thinks while the sub-agents work in parallel.

### 2. Spawn sub-agents

Spawn 3+ sub-agents in parallel using `spawn_agent`. Each must produce a **radically different** interface for the deepened module.

Prompt each sub-agent with a separate technical brief (file paths, coupling details, dependency category from [DEEPENING.md](DEEPENING.md), what sits behind the seam). The brief is independent of the user-facing problem-space explanation in Step 1. Give each agent a different design constraint:

- Agent 1: "Minimize the interface — aim for 1–3 entry points max. Maximise leverage per entry point."
- Agent 2: "Maximise flexibility — support many use cases and extension."
- Agent 3: "Optimise for the most common caller — make the default case trivial."
- Agent 4 (if applicable): "Design around ports & adapters for cross-seam dependencies."

Include both [LANGUAGE.md](LANGUAGE.md) vocabulary and CONTEXT.md vocabulary in the brief so each sub-agent names things consistently with the architecture language and the project's domain language.

Each sub-agent outputs:

1. Interface (types, methods, params — plus invariants, ordering, error modes)
2. Usage example showing how callers use it
3. What the implementation hides behind the seam
4. Dependency strategy and adapters (see [DEEPENING.md](DEEPENING.md))
5. Trade-offs — where leverage is high, where it's thin

### 3. Present and compare

Present designs sequentially so the user can absorb each one, then compare them in prose. Contrast by **depth** (leverage at the interface), **locality** (where change concentrates), and **seam placement**.

After comparing, give your own recommendation: which design you think is strongest and why. If elements from different designs would combine well, propose a hybrid. Be opinionated — the user wants a strong read, not a menu.

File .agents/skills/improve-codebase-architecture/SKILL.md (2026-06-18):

---
name: improve-codebase-architecture
description: Find deepening opportunities in a codebase, informed by the domain language in CONTEXT.md and the decisions in docs/adr/. Use when the user wants to improve architecture, find refactoring opportunities, consolidate tightly-coupled modules, or make a codebase more testable and AI-navigable.
---

# Improve Codebase Architecture

Surface architectural friction and propose **deepening opportunities** — refactors that turn shallow modules into deep ones. The aim is testability and AI-navigability.

## Glossary

Use these terms exactly in every suggestion. Consistent language is the point — don't drift into "component," "service," "API," or "boundary." Full definitions in [LANGUAGE.md](LANGUAGE.md).

- **Module** — anything with an interface and an implementation (function, class, package, slice).
- **Interface** — everything a caller must know to use the module: types, invariants, error modes, ordering, config. Not just the type signature.
- **Implementation** — the code inside.
- **Depth** — leverage at the interface: a lot of behaviour behind a small interface. **Deep** = high leverage. **Shallow** = interface nearly as complex as the implementation.
- **Seam** — where an interface lives; a place behaviour can be altered without editing in place. (Use this, not "boundary.")
- **Adapter** — a concrete thing satisfying an interface at a seam.
- **Leverage** — what callers get from depth.
- **Locality** — what maintainers get from depth: change, bugs, knowledge concentrated in one place.

Key principles (see [LANGUAGE.md](LANGUAGE.md) for the full list):

- **Deletion test**: imagine deleting the module. If complexity vanishes, it was a pass-through. If complexity reappears across N callers, it was earning its keep.
- **The interface is the test surface.**
- **One adapter = hypothetical seam. Two adapters = real seam.**

This skill is _informed_ by the project's domain model. The domain language gives names to good seams; ADRs record decisions the skill should not re-litigate.

## Process

### 1. Explore

Read the project's domain glossary (`CONTEXT.md`) and any ADRs in `docs/adr/` in the area you're touching first. If `CONTEXT.md` doesn't exist yet, note that — you'll create it lazily as terms crystallize.

Then use `spawn_agent` to walk the codebase. Don't follow rigid heuristics — explore organically and note where you experience friction:

- Where does understanding one concept require bouncing between many small modules?
- Where are modules **shallow** — interface nearly as complex as the implementation?
- Where have pure functions been extracted just for testability, but the real bugs hide in how they're called (no **locality**)?
- Where do tightly-coupled modules leak across their seams?
- Which parts of the codebase are untested, or hard to test through their current interface?

Apply the **deletion test** to anything you suspect is shallow: would deleting it concentrate complexity, or just move it? A "yes, concentrates" is the signal you want.

### 2. Present candidates as an HTML report

Write a self-contained HTML file to the OS temp directory so nothing lands in the repo. Resolve the temp dir from `$TMPDIR` or `$TEMP`, falling back to `/tmp`, and write to `<tmpdir>/architecture-review-<timestamp>.html` so each run gets a fresh file. Open it for the user via the `terminal` tool — `xdg-open <path>` on Linux, `open <path>` on macOS, `start <path>` on Windows — and tell them the absolute path.

The report uses **Tailwind via CDN** for layout and styling, and **Mermaid via CDN** for diagrams where a graph/flow/sequence reliably communicates the structure. Mix Mermaid with hand-crafted CSS/SVG visuals — use Mermaid when relationships are graph-shaped (call graphs, dependencies, sequences), and hand-built divs/SVG when you want something more editorial (mass diagrams, cross-sections, collapse animations). Each candidate gets a **before/after visualisation**. Be visual.

For each candidate, the same template as before, but rendered as a card:

- **Files** — which files/modules are involved
- **Problem** — why the current architecture is causing friction
- **Solution** — plain English description of what would change
- **Benefits** — explained in terms of locality and leverage, and how tests would improve
- **Before / After diagram** — side-by-side, custom-drawn, illustrating the shallowness and the deepening
- **Recommendation strength** — one of `Strong`, `Worth exploring`, `Speculative`, rendered as a badge

End the report with a **Top recommendation** section: which candidate you'd tackle first and why.

**Use CONTEXT.md vocabulary for the domain, and [LANGUAGE.md](LANGUAGE.md) vocabulary for the architecture.** If `CONTEXT.md` defines "Order," talk about "the Order intake module" — not "the FooBarHandler," and not "the Order service."

**ADR conflicts**: if a candidate contradicts an existing ADR, only surface it when the friction is real enough to warrant revisiting the ADR. Mark it clearly in the card (e.g. a warning callout: _"contradicts ADR-0007 — but worth reopening because…"_). Don't list every theoretical refactor an ADR forbids.

See [HTML-REPORT.md](HTML-REPORT.md) for the full HTML scaffold, diagram patterns, and styling guidance.

Do NOT propose interfaces yet. After the file is written, ask the user: "Which of these would you like to explore?"

### 3. Grilling loop

Once the user picks a candidate, drop into a grilling conversation (see the `grill-me` skill for discipline). Walk the design tree with the user — constraints, dependencies, the shape of the deepened module, what sits behind the seam, what tests survive.

Side effects happen inline as decisions crystallize:

- **Naming a deepened module after a concept not in `CONTEXT.md`?** Add the term to `CONTEXT.md`. Create the file lazily if it doesn't exist. Format as a glossary entry with a definition and aliases.
- **Sharpening a fuzzy term during the conversation?** Update `CONTEXT.md` right there.
- **User rejects the candidate with a load-bearing reason?** Offer to record it as an ADR in `docs/adr/`, framed as: _"Want me to record this as an ADR so future architecture reviews don't re-suggest it?"_ Only offer when the reason would actually be needed by a future explorer to avoid re-suggesting the same thing — skip ephemeral reasons ("not worth it right now") and self-evident ones.
- **Want to explore alternative interfaces for the deepened module?** See [INTERFACE-DESIGN.md](INTERFACE-DESIGN.md).

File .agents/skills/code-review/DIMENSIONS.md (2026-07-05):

# Review Dimension Instructions

Each dimension below is a self-contained prompt that can be handed to a sub-agent along with the diff context.

---

## Safety & Correctness

You are reviewing an embedded Rust project (no_std, embassy, RP2350). Focus only on safety and correctness.

**Check for:**

1. **Unsafe blocks** — every `unsafe { }` must be justified. Flag any that:
   - Are unnecessary (the operation has a safe equivalent)
   - Lack a `// SAFETY:` comment explaining the invariant
   - Invoke FFI or raw pointer manipulation without a clear safety argument
   - Interact with MMIO/pac without clear ownership documentation

2. **Panic paths** — the project denies `unwrap_used` and `expect_used` via clippy. Flag any remaining:
   - `unwrap()`, `expect()`, explicit `panic!()`
   - Array indexing without bounds checks (in release)
   - Division/modulo without zero-checks where the divisor is dynamic
   - `unwrap_unchecked` or similar

3. **Lock ordering** — the project has a documented lock order: Power → Calibration → Perception → Motion. Flag:
   - Mutex acquisitions that violate this order
   - Potential deadlocks from holding a lock across an `.await`
   - `CriticalSectionRawMutex` held for too long (embassy requires short critical sections)

4. **Interrupt safety** — flag:
   - Shared mutable state accessed from both interrupt and task context without proper synchronization
   - `static mut` usage (the project uses `Mutex` and `Atomic*` — flag deviations)
   - `Cell`/`RefCell` used in ways that could panic at runtime

5. **Resource ownership** — flag:
   - Multiple tasks taking ownership of the same peripheral
   - `static` peripheral handles that could cause use-after-move
   - `Send`/`Sync` violations (embassy tasks are not `Send`)

**Output format:** `[{file, line, severity: "critical"|"warning"|"note", category: "safety", title, detail}]`

Be specific — include line numbers, the unsafe/fallible construct, and a one-sentence fix suggestion.

---

## Embedded Concerns

You are reviewing an embedded Rust project targeting RP2350 (Cortex-M33, no_std, embassy). Focus only on embedded-specific concerns.

**Check for:**

1. **Stack usage** — embassy tasks have fixed stack sizes (see `CORE1_STACK` in main.rs). Flag:
   - Large stack allocations (arrays > 512 bytes on the stack)
   - Recursive functions (embedded stacks are small)
   - `#[embassy_executor::task]` functions that look stack-heavy

2. **Heap allocations** — this is a no_std project. Flag:
   - Any use of `alloc::` or `Box`, `Vec`, `String` from std
   - `heapless` types that could exceed their const-generic capacity at runtime
   - `format!()` or other allocation-requiring macros (use `defmt!` logging instead)

3. **Peripheral conflicts** — flag:
   - GPIO pins used by multiple peripherals simultaneously
   - I2C/SPI bus sharing issues
   - PIO state machine conflicts
   - DMA channel conflicts

4. **No_std compliance** — flag:
   - `use std::*` imports
   - Functions that require `std` (filesystem, networking, threading)
   - Floating-point operations in interrupt context (soft-float targets may have issues)

5. **Power & timing** — flag:
   - Busy-wait loops without yield/sleep (wastes battery)
   - Missing `embassy_time` timeouts on async operations that could hang
   - Hard-coded delays that should be derived from timing requirements

**Output format:** `[{file, line, severity: "critical"|"warning"|"note", category: "embedded", title, detail}]`

---

## Architecture & Depth

You are reviewing an embedded Rust project for architectural quality. Use the vocabulary from the project's architecture language:

- **Module**: anything with an interface and an implementation
- **Interface**: everything a caller must know (types, invariants, error modes, ordering, config)
- **Depth**: behaviour behind a small interface (deep = high leverage, shallow = interface ≈ implementation)
- **Seam**: where an interface lives; a place behaviour can be altered without editing in place
- **Adapter**: a concrete thing satisfying an interface at a seam
- **Leverage**: what callers get from depth
- **Locality**: change/bugs/knowledge concentrated in one place

**Check for:**

1. **Shallow modules** — where the interface nearly matches the implementation. Apply the deletion test: if you deleted this module, would complexity vanish (pass-through) or reappear across N callers (earning its keep)?

2. **Seam leakage** — where implementation details of one module leak through the interface into another. Flag: modules importing internal types from sibling modules, callers reaching behind the interface.

3. **Tightly-coupled modules** — modules that change together, are tested together, and can't be understood separately. Flag when a change in one module forces predictable changes in another.

4. **One-adapter seams** — seams with only one adapter are hypothetical. Flag these. Two+ adapters justify the seam.

5. **Lost locality** — logic for one concern spread across multiple modules. Pure functions extracted just for testability but the real bugs hide in how they're called.

6. **ADR conflicts** — check findings against the ADRs in `docs/adr/`. Flag contradictions with existing decisions.

**Output format:** `[{file, line, severity: "critical"|"warning"|"note", category: "architecture", title, detail}]`

Keep it concrete — name specific modules, interfaces, and seams. Use the project's domain vocabulary from CONTEXT.md.

---

## Style & Idioms

You are reviewing an embedded Rust project for code style and idiom consistency. Do not flag trivial formatting issues (rustfmt handles those). Focus on meaningful style concerns.

**Check for:**

1. **Naming** — flag:
   - Acronyms not consistently cased (e.g. `Imu` vs `IMU` — look at the project convention)
   - Generic names in specific contexts (`data`, `info`, `result`, `tmp`)
   - Module/file names that don't match their primary type/concern
   - No new acronyms introduced without glossary entries

2. **Documentation** — flag:
   - Public items without doc comments (`///` or `//!`)
   - Doc comments that are just the item name repeated
   - Missing `# Safety` sections on unsafe functions
   - Missing `# Panics` sections on functions that can panic
   - Missing `# Errors` sections on fallible functions

3. **Pattern consistency** — flag deviations from established project patterns:
   - The project uses `defmt::Format` derive on public types — flag missing derives
   - The project uses `#[embassy_executor::task]` for async tasks — flag raw async fn spawns
   - The project uses `CriticalSectionRawMutex` + `Mutex` for shared state — flag other synchronization
   - The project uses `Channel` from `embassy_sync` — flag other channel types

4. **Clippy** — flag:
   - Patterns that `clippy::pedantic` or `clippy::nursery` would catch (the project enables these)
   - `as` casts that could silently truncate (use `.into()` or `try_into()`)
   - Unnecessary clones or copies
   - `let _ = ...` where the result should be handled

5. **Error handling** — flag:
   - Swallowed errors (the project denies `unwrap`/`expect`)
   - Missing `#[must_use]` on result-returning functions
   - Inconsistent error type usage

**Output format:** `[{file, line, severity: "critical"|"warning"|"note", category: "style", title, detail}]`

---

## Domain Model

You are reviewing an embedded robot project for domain model consistency. The project maintains a domain glossary in `CONTEXT.md` with carefully chosen terms and "Avoid" aliases.

**Check for:**

1. **Glossary consistency** — flag any use of terms listed as "Avoid" in CONTEXT.md (e.g. "scan" instead of "sweep", "heading error" instead of "accumulated drift", "step" instead of "leg").

2. **New concepts** — flag any new domain concept introduced in the changes that doesn't have a glossary entry yet. Propose a definition and canonical name. Check if the concept already exists under a different name.

3. **Overloaded terms** — flag when an existing glossary term is being used inconsistently (e.g. "gap" used to mean something different from the glossary definition).

4. **ADR references** — flag when the code references a concept decided in an ADR but uses different terminology than the ADR itself.

5. **Missing context** — flag when a new module or type name introduces a concept that should be in the glossary but isn't. E.g. a new module called `obstacle_fusion` should have "Obstacle Fusion" in the glossary.

**Output format:** `[{file, line, severity: "critical"|"warning"|"note", category: "domain", title, detail}]`

For each finding, propose the exact glossary entry text or the term that should be used instead.

---

## Testability

You are reviewing an embedded Rust project for testability. The project targets no_std embassy on RP2350, so on-target testing is limited, but module-level testing is possible where seams exist.

**Check for:**

1. **Untestable paths** — flag new logic that has no seams for testing:
   - Logic embedded directly in `#[embassy_executor::task]` functions (can't be called from tests)
   - Logic that takes concrete peripheral types instead of traits
   - Time-dependent logic without a clock abstraction

2. **Missing tests** — flag:
   - New pure functions or modules with no corresponding tests
   - Previous tests that should be updated for changed behavior but weren't
   - Boundary conditions not covered by existing tests

3. **Test quality** — flag:
   - Tests that test implementation details rather than external behavior
   - Tests with no assertions (or assertions that can't fail)
   - Tests that depend on timing (sleep/delay) rather than determinism

4. **Test seams** — flag opportunities:
   - Where extracting an interface would enable testing (one real adapter on-target, one mock adapter in tests)
   - Where existing seams could be used but aren't (e.g. a trait bound that could accept a test double)

5. **Hardware coupling** — flag:
   - New code that directly accesses hardware registers instead of going through HAL abstractions
   - Code that assumes specific hardware configuration without making it injectable

**Output format:** `[{file, line, severity: "critical"|"warning"|"note", category: "testability", title, detail}]`

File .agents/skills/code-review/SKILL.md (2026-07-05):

---
name: code-review
description: Review staged/unstaged changes plus commits ahead of origin/main. Produces an HTML report in the OS temp dir, then grills the user with docs on findings.
---

# Code Review

Review the working tree (tracked + untracked changes) and commits ahead of `origin/main`. The output is a self-contained HTML report in the OS temp dir, followed by a grilling session where findings can crystallize into ADRs or glossary updates.

## Process

### 1. Gather context

Run these in parallel:

- `git --no-pager diff HEAD` — unstaged + staged tracked changes
- `git --no-pager diff --cached` — staged-only changes (to distinguish from unstaged)
- `git --no-pager log origin/main..HEAD --oneline --no-decorate` — commits ahead of origin/main
- `git --no-pager log origin/main..HEAD --stat` — files touched in those commits
- `git --no-pager log origin/main..HEAD -p` — full diff of commits ahead
- `ls-files --others --exclude-standard` — untracked files

Read `CONTEXT.md` and any ADRs in `docs/adr/` to ground the review in the project's domain language and known architectural decisions.

### 2. Plan the review

From the diff scope, decide which review dimensions to delegate. Don't spawn an agent for dimensions that have no relevant changes (e.g. no new unsafe blocks → skip safety agent). The available dimensions:

| Dimension | Focus | When to skip |
|---|---|---|
| **Safety & correctness** | `unsafe` blocks, panic paths, `unwrap`/`expect`, lock ordering, interrupt safety, `static mut` | No new unsafe/fallible paths |
| **Embedded concerns** | Stack usage, allocation patterns, `no_std` compliance, peripheral conflicts, interrupt priorities, DMA hazards | Only pure-logic changes |
| **Architecture & depth** | Module seams, shallowness, leakage, leverage, locality (using `improve-codebase-architecture` vocabulary) | Trivial refactors with no structural change |
| **Style & idioms** | Naming conventions, doc comments, clippy adherence, `defmt::Format` derives, pattern consistency | Cosmetic-only changes (the agent still runs but fast-paths) |
| **Domain model** | Consistency with `CONTEXT.md` terms, new concepts needing glossary entries, ADR conflicts | No new domain concepts introduced |
| **Testability** | Test seams, untestable paths, missing test coverage for new logic, test quality | No new logic or only dead-code removal |

If the diff is small (≤3 files, ≤100 lines), skip the sub-agent fan-out and review directly. For anything larger, spawn sub-agents.

### 3. Spawn sub-agents (parallel)

For each applicable dimension, spawn one agent. Each gets:
- The full diff context (commits + working tree)
- The relevant subset of `CONTEXT.md` terms
- Dimension-specific instructions (see [DIMENSIONS.md](DIMENSIONS.md))
- An output schema: `[{file, line, severity, category, title, detail}]`

Agents run in parallel. Collect all findings when done.

### 4. Synthesize findings into an HTML report

Write a self-contained HTML file to the OS temp dir. Resolve the temp dir from `$TMPDIR` or `$TEMP`, falling back to `/tmp`, and write to `<tmpdir>/code-review-<timestamp>.html`. Open it via `xdg-open <path>` (Linux), `open <path>` (macOS), or `start <path>` (Windows).

See [HTML-REPORT.md](HTML-REPORT.md) for the scaffold and styling.

The report structure:

- **Header**: branch name, review scope (N commits ahead + working tree), timestamp, total finding count
- **Summary cards**: one per dimension, showing count of findings by severity (🔴 Critical / 🟡 Warning / 🔵 Note)
- **Findings table**: sortable, filterable table with columns: File, Line, Severity, Category, Title
- **Detail panels**: click a finding → expand inline showing the detail explanation and the relevant code snippet
- **Top issues**: the 3 most actionable findings, with concrete fix suggestions

### 5. Grill with docs

After the user has seen the report, drop into a grilling conversation. Walk findings by severity (critical first). For each finding the user wants to act on:

- **Architectural finding?** Offer to record as an ADR: "Want me to record this as ADR-NNNN in `docs/adr/`?"
- **New domain concept surfaced?** Offer to add it to `CONTEXT.md`: "This introduces the concept of X — want me to add it to the glossary?"
- **Pattern to encode?** Offer to encode it in a testing decision or ADR.

Use the grilling discipline from the `grill-me` skill: one question at a time, walk each branch, resolve dependencies before moving on.

Ask: "Which findings should we act on first?"

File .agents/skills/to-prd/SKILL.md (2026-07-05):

---
name: to-prd
description: Turn the current conversation into a PRD and write it to docs/prd/ — no interview, just synthesis of what you've already discussed.
disable-model-invocation: true
---

This skill takes the current conversation context and codebase understanding and produces a PRD. Do NOT interview the user — just synthesize what you already know.

## Process

1. Explore the repo to understand the current state of the codebase, if you haven't already. Use the project's domain glossary vocabulary throughout the PRD, and respect any ADRs in the area you're touching.

2. Sketch out the seams at which you're going to test the feature. Existing seams should be preferred to new ones. Use the highest seam possible. If new seams are needed, propose them at the highest point you can. The fewer seams across the codebase, the better - the ideal number is one.

Check with the user that these seams match their expectations.

3. Write the PRD using the template below. Save it to `docs/prd/` as a markdown file. Derive the filename from the title: lowercase, hyphenated slug (e.g. `docs/prd/mobile-check-deposit.md`). Create the `docs/prd/` directory lazily — only when the first PRD is needed.

<prd-template>

## Problem Statement

The problem that the user is facing, from the user's perspective.

## Solution

The solution to the problem, from the user's perspective.

## User Stories

A LONG, numbered list of user stories. Each user story should be in the format of:

1. As an <actor>, I want a <feature>, so that <benefit>

<user-story-example>
1. As a mobile bank customer, I want to see balance on my accounts, so that I can make better informed decisions about my spending
</user-story-example>

This list of user stories should be extremely extensive and cover all aspects of the feature.

## Implementation Decisions

A list of implementation decisions that were made. This can include:

- The modules that will be built/modified
- The interfaces of those modules that will be modified
- Technical clarifications from the developer
- Architectural decisions
- Schema changes
- API contracts
- Specific interactions

Do NOT include specific file paths or code snippets. They may end up being outdated very quickly.

Exception: if a prototype produced a snippet that encodes a decision more precisely than prose can (state machine, reducer, schema, type shape), inline it within the relevant decision and note briefly that it came from a prototype. Trim to the decision-rich parts — not a working demo, just the important bits.

## Testing Decisions

A list of testing decisions that were made. Include:

- A description of what makes a good test (only test external behavior, not implementation details)
- Which modules will be tested
- Prior art for the tests (i.e. similar types of tests in the codebase)

## Out of Scope

A description of the things that are out of scope for this PRD.

## Further Notes

Any further notes about the feature.

</prd-template>

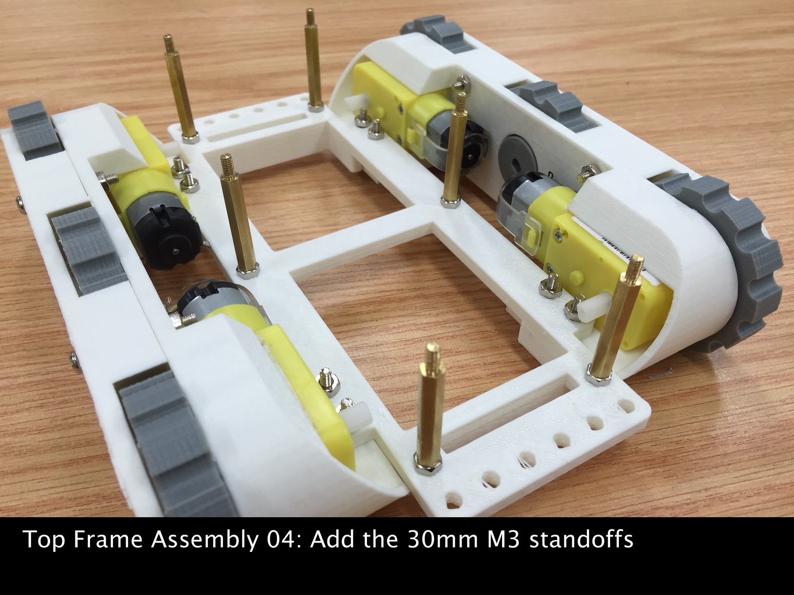
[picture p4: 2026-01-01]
misc/chassis/proto-tank/images/topFrame04.jpg

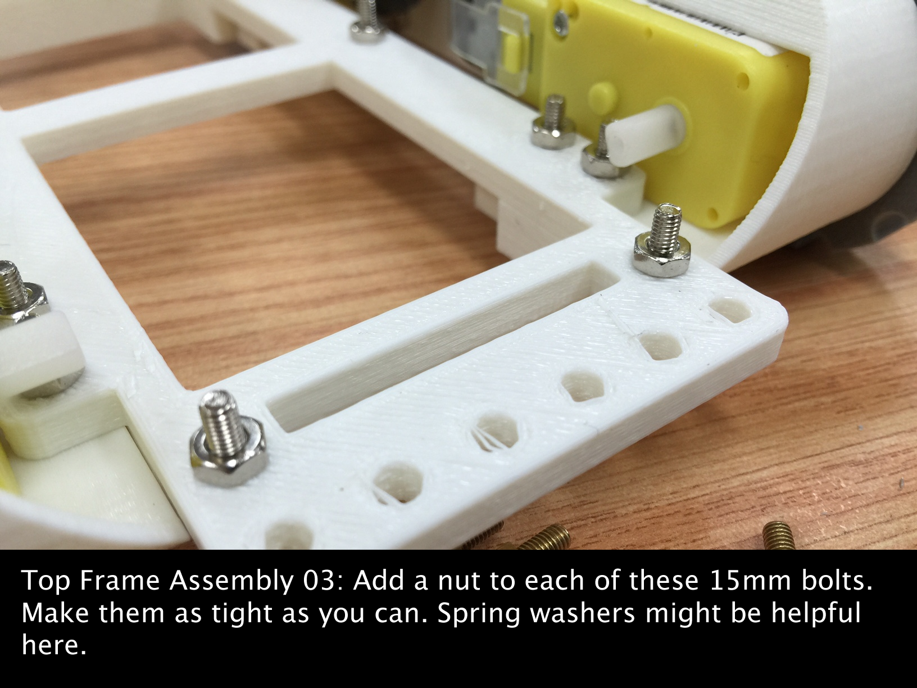
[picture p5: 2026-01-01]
misc/chassis/proto-tank/images/TopFrame03.png

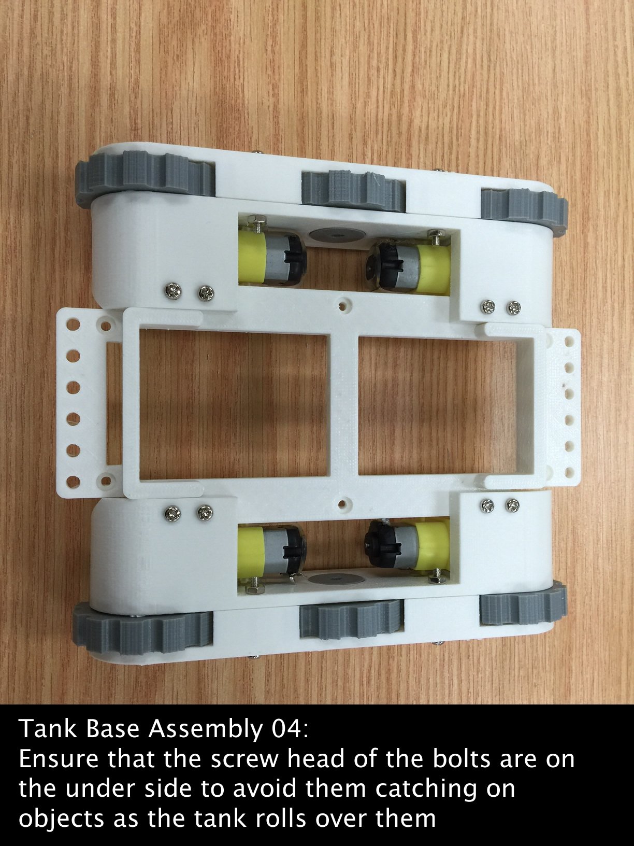
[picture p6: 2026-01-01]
misc/chassis/proto-tank/images/TankBase04.jpg

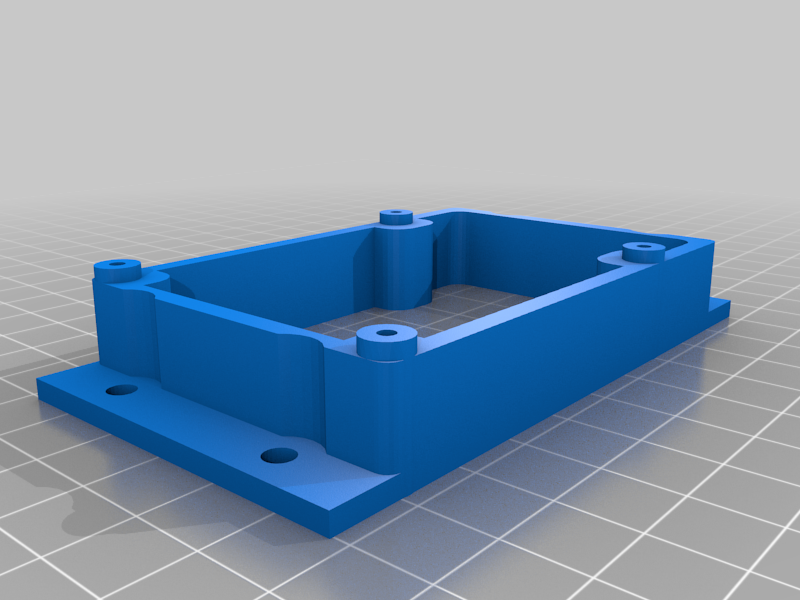
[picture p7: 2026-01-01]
misc/chassis/proto-tank/images/Accessory_RPi_Holder_Perpendicular.png

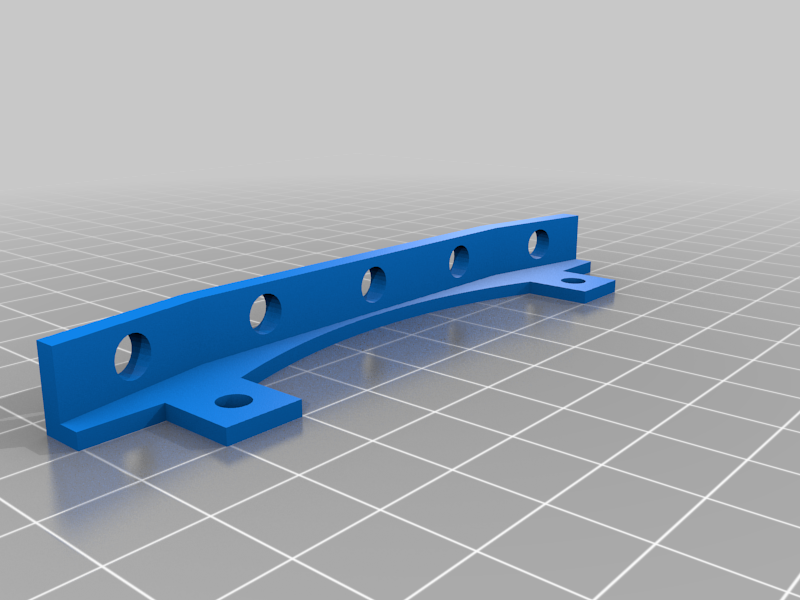
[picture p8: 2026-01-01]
misc/chassis/proto-tank/images/Accessory_lightBar.png

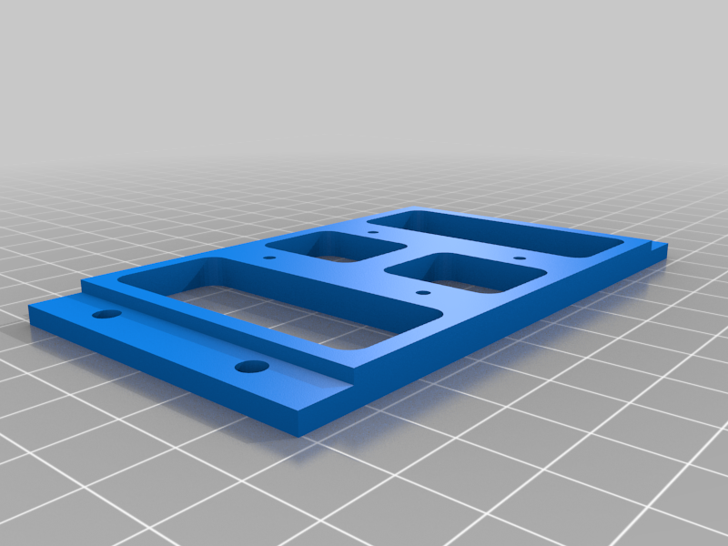
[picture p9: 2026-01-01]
misc/chassis/proto-tank/images/Accessory_MiniTiltPanHolder.png

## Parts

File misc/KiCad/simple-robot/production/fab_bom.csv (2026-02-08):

Designator | Footprint | Quantity | Value | LCSC Part #
B1 | LM2596_Module | 1 | LM2596 Module
C1, C7 | CP_Radial_D6.3mm_P2.50mm | 2 | 220uF
C10, C11, C12, C13, C14, C15, C16, C19, C2, C20, C21, C22, C23, C24, C26, C3, C4, C5, C6, C8, C9 | C_Disc_D5.0mm_W2.5mm_P2.50mm | 21 | 100nF_Ceramic
C17 | CP_Radial_D6.3mm_P2.50mm | 1 | 10uF_10V
C18 | CP_Radial_D16.0mm_P7.50mm | 1 | 4700uF_16V
C25 | CP_Radial_D5.0mm_P2.00mm | 1 | 10uF_16V
D1, D3 | D_DO-41_SOD81_P7.62mm_Horizontal | 2 | 1N5819
I1 | ICM-20948-module | 1 | ~
J1 | JST_PH_B2B-PH-K_1x02_P2.00mm_Vertical | 1 | MotLA
J10 | TerminalBlock_Phoenix_PT-1,5-2-5.0-H_1x02_P5.00mm_Horizontal | 1 | Screw_Terminal_2_P5.00mm
J11 | JST_EH_B4B-EH-A_1x04_P2.50mm_Vertical | 1 | JSTHCSR04
J12 | JST_PH_B3B-PH-K_1x03_P2.00mm_Vertical | 1 | IR_RF
J13 | JST_PH_B3B-PH-K_1x03_P2.00mm_Vertical | 1 | IR_LF
J14 | JST_EH_B4B-EH-A_1x04_P2.50mm_Vertical | 1 | GV
J15 | JST_EH_B4B-EH-A_1x04_P2.50mm_Vertical | 1 | JST RF-LOG
J16 | JST_EH_B2B-EH-A_1x02_P2.50mm_Vertical | 1 | RF_PWR
J2 | JST_PH_B2B-PH-K_1x02_P2.00mm_Vertical | 1 | MotLB
J3 | JST_EH_B3B-EH-A_1x03_P2.50mm_Vertical | 1 | Servo
J4 | JST_PH_B2B-PH-K_1x02_P2.00mm_Vertical | 1 | MotRA
J5 | JST_PH_B2B-PH-K_1x02_P2.00mm_Vertical | 1 | MotRB
J6 | JST_PH_B3B-PH-K_1x03_P2.00mm_Vertical | 1 | ENC_LF
J7 | JST_PH_B3B-PH-K_1x03_P2.00mm_Vertical | 1 | ENC_LR
J8 | JST_PH_B3B-PH-K_1x03_P2.00mm_Vertical | 1 | ENC_RF
J9 | JST_PH_B3B-PH-K_1x03_P2.00mm_Vertical | 1 | ENC_RR
LED1 | LED_D5.0mm-4_RGB_Wide_Pins | 1 | LED_5mm_RGB_Kcom_RKGB
LS_1, LS_2, LS_3 | Level shifter 4 bi-dir | 3 | Level Shifter
MD1 | TB6612FNG motor driver carrier | 1 | LeftTrack
MD2 | TB6612FNG motor driver carrier | 1 | RightTrack
OLED1 | SSD1306 | 1 | ~
P1 | PCA9555 Port Expander | 1 | Port Expander
R10, R11 | R_Axial_DIN0207_L6.3mm_D2.5mm_P10.16mm_Horizontal | 2 | 220ohm
R2, R3 | R_Axial_DIN0207_L6.3mm_D2.5mm_P10.16mm_Horizontal | 2 | 47ohm
R4, R7 | R_Axial_DIN0207_L6.3mm_D2.5mm_P10.16mm_Horizontal | 2 | 20k
R5, R6 | R_Axial_DIN0207_L6.3mm_D2.5mm_P10.16mm_Horizontal | 2 | 1k
R8 | R_Axial_DIN0207_L6.3mm_D2.5mm_P10.16mm_Horizontal | 1 | 10k
R9 | R_Axial_DIN0207_L6.3mm_D2.5mm_P10.16mm_Horizontal | 1 | 330ohm
SW1 | RotaryEncoder_Alps_EC11E-Switch_Vertical_H20mm | 1 | RotaryEncoder_Switch
U2 | DIP-16_W7.62mm_LongPads | 1 | CD4049UB

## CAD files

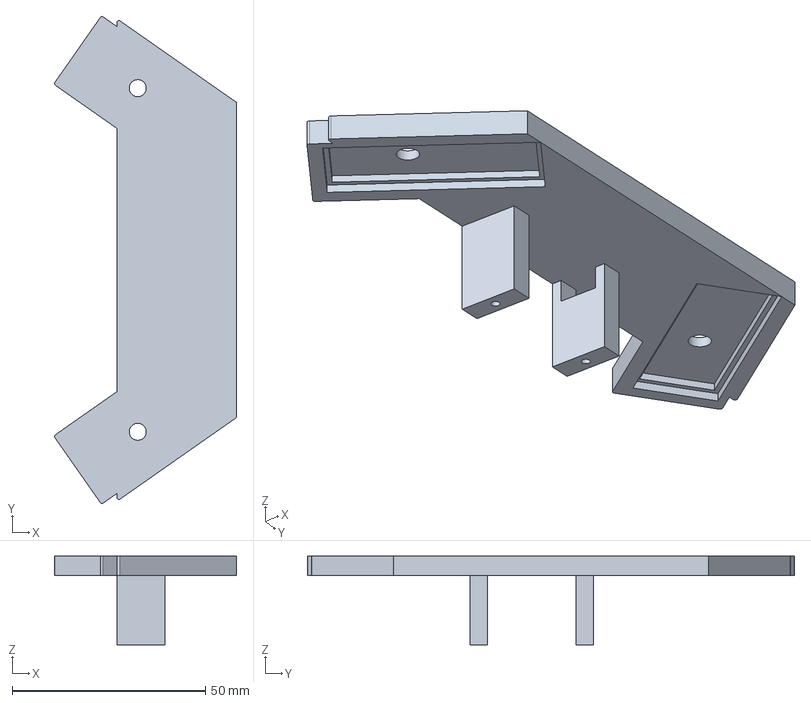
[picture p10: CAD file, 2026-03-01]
misc/chassis/front sensor array.FCStd
47.2 x 126.1 x 23.0 mm

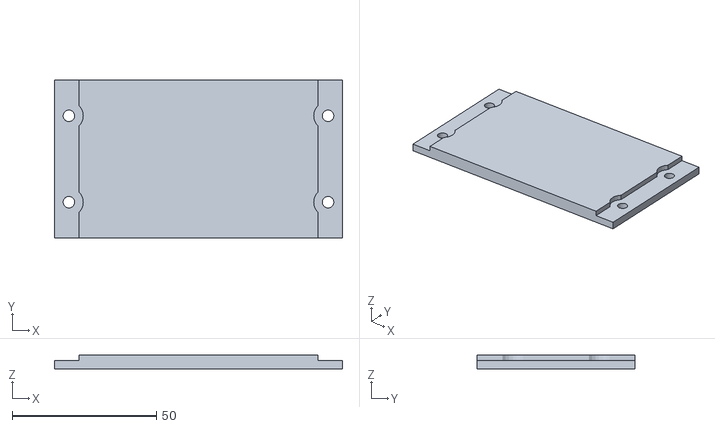
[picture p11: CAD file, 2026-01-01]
misc/chassis/proto-tank/files/Accessory_breadBoard.stl
100.0 x 55.0 x 5.00

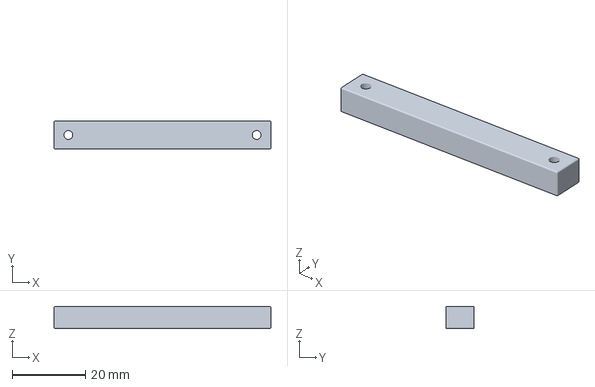
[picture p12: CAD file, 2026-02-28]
misc/chassis/battey holder bar.3mf
59.1 x 7.70 x 6.00 mm

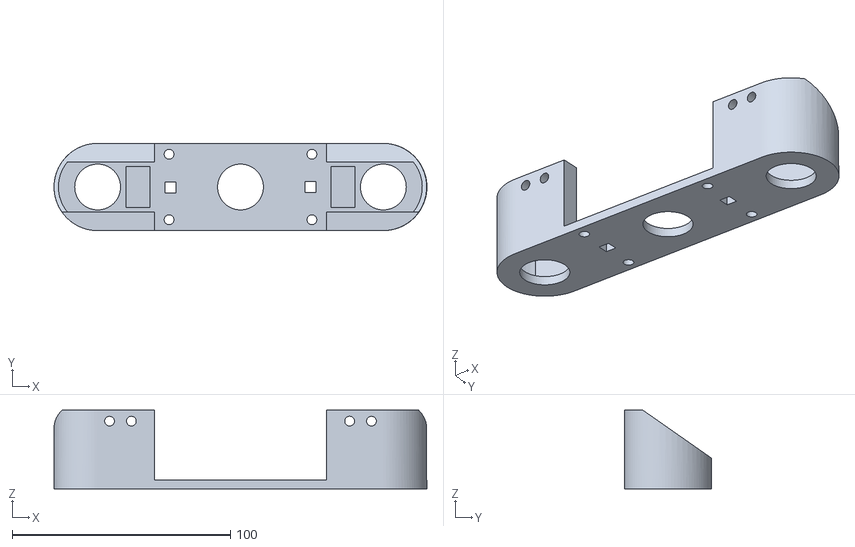
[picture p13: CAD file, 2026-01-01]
misc/chassis/proto-tank/files/ProtoTank_trackinnerFrame.stl
170.9 x 40.0 x 36.0

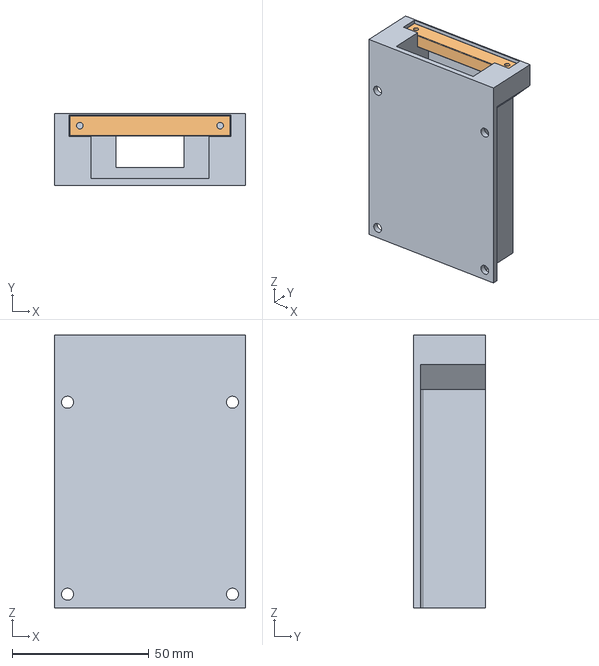
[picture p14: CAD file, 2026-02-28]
misc/chassis/battery holder.FCStd
70.0 x 26.3 x 99.8 mm
Case
Bar

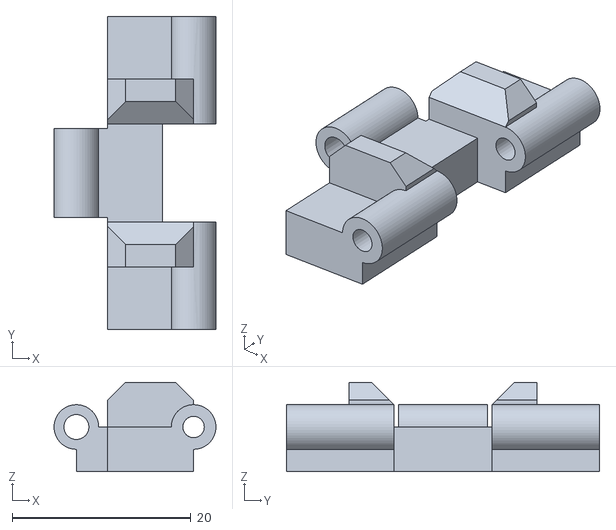
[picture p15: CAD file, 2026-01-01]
misc/chassis/proto-tank/files/track_1_4.stl
18.1 x 35.0 x 10.0

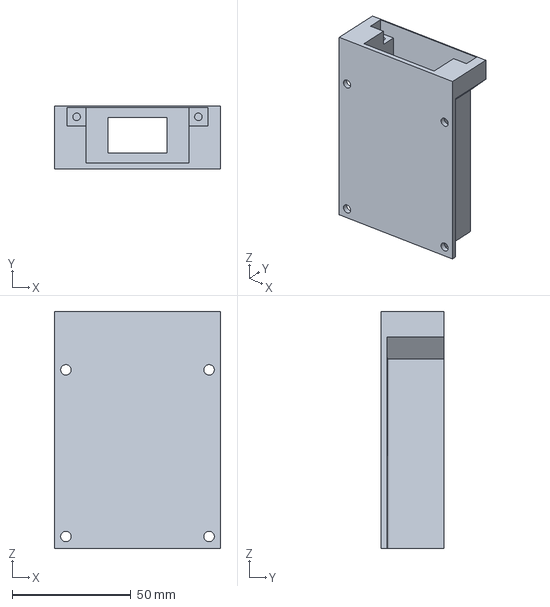
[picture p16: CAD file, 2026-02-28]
misc/chassis/battey holder case.3mf
70.0 x 26.3 x 99.8 mm

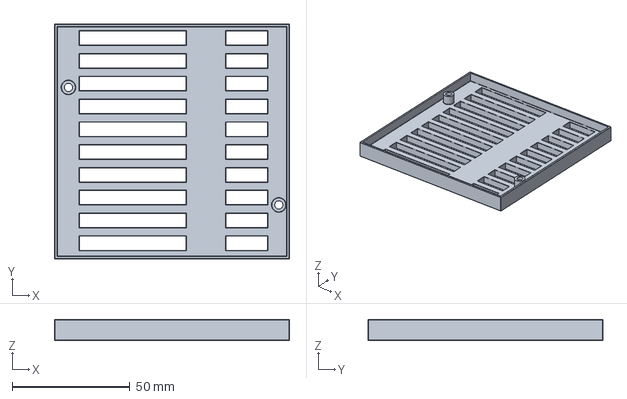
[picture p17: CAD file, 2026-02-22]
misc/chassis/PCB mount.FCStd
100.0 x 100.0 x 9.00 mm

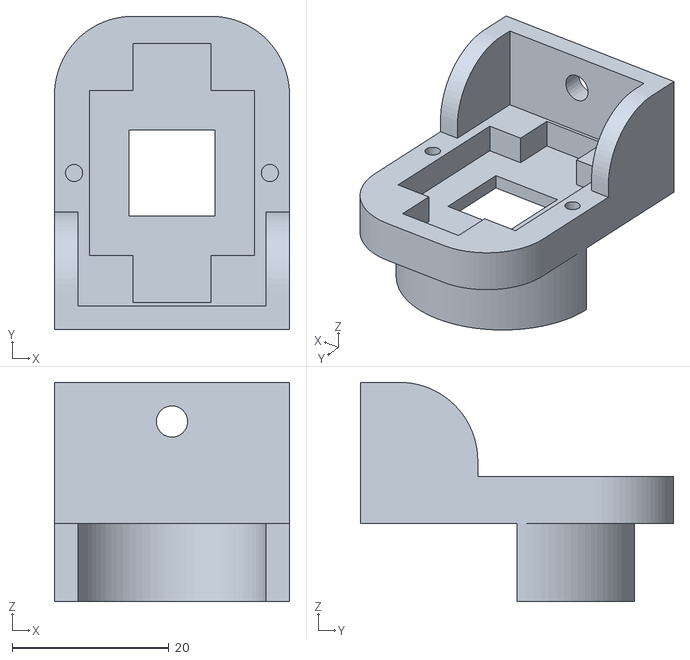
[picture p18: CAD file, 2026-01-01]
misc/chassis/proto-tank/files/Accessory_LED_Chip_Holder.stl
30.0 x 40.0 x 28.0

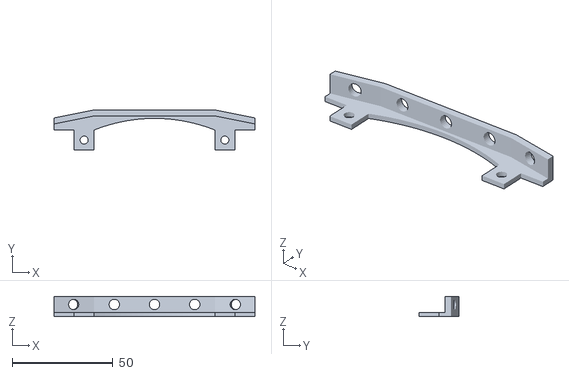
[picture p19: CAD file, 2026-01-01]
misc/chassis/proto-tank/files/Accessory_lightBar.stl
100.0 x 20.0 x 10.0

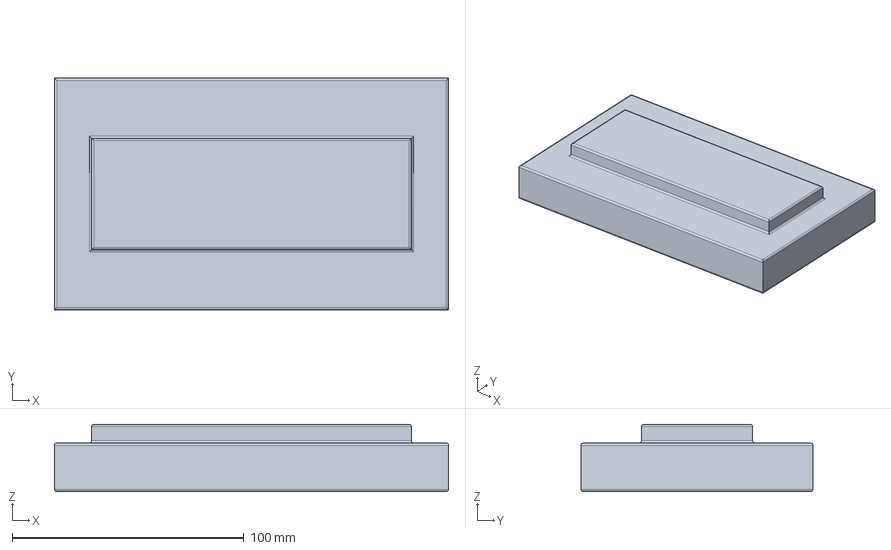
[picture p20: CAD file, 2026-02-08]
misc/chassis/Riser.FCStd
170.0 x 100.0 x 29.0 mm

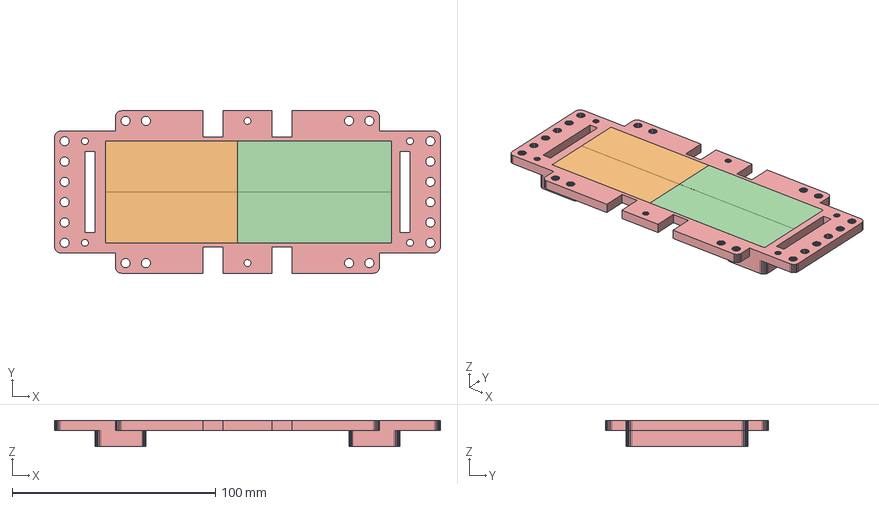
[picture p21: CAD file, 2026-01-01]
misc/chassis/BaseFrame - edit.FCStd
190.0 x 80.0 x 13.0 mm
Extrude - Inner Strength

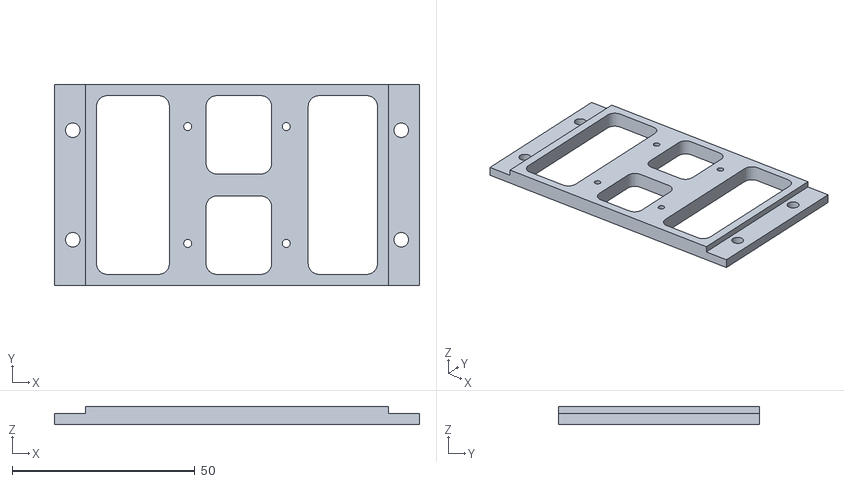
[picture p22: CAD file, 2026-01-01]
misc/chassis/proto-tank/files/Accessory_MiniTiltPanHolder.stl
100.0 x 55.0 x 5.00

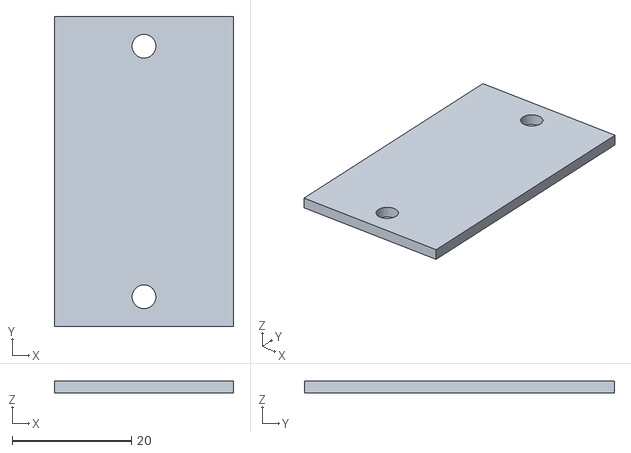
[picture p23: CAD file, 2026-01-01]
misc/chassis/proto-tank/files/Accessory_BatteryCover.stl
30.0 x 52.0 x 2.00

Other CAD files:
misc/chassis/proto-tank/files/track_1_35.stl
misc/chassis/track pin print project.3mf
misc/chassis/proto-tank/files/track_1_45.stl
misc/chassis/track pin.3mf
misc/chassis/BaseFrame - edit.3mf
misc/chassis/BaseFrame - edit.stl
misc/chassis/PCB mount.3mf
misc/chassis/front sensor array.3mf
misc/chassis/hc-sr04 mount.3mf
misc/chassis/hc-sr04 mount.FCStd
misc/chassis/print project.3mf
misc/chassis/proto-tank/files/Accessory_BaseTrayL298N.stl
misc/chassis/proto-tank/files/Accessory_BatteryCase.stl
misc/chassis/proto-tank/files/Accessory_LCD_Holder.stl
misc/chassis/proto-tank/files/Accessory_LED_Chip_Brace.stl
misc/chassis/proto-tank/files/Accessory_RPiHolder.stl
misc/chassis/proto-tank/files/Accessory_RPi_Holder_Perpendicular.stl
misc/chassis/proto-tank/files/Accessory_Sharp2Y0A02.stl
misc/chassis/proto-tank/files/Accessory_Static_RPi_CameraHolder.stl
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

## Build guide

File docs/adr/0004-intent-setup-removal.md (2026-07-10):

# Delete IntentSetup — intent init owns sensor lifecycle

The `IntentSetup` enum declared what sensor streams each intent needed during setup. Control modules returned a descriptor from `init()`; the `dispatch` executed it via `execute_intent_setup`. In practice, only `EncoderSettle` (brake/coast) was used; `RotationImu` was dead (rotation's init started IMU itself) and `DistanceImuAndEncoder` was partially bypassed (dispatch did most setup inline in `handle_drive_distance` before the descriptor was executed).

After making `handle_drive_distance` consistent with other intents and giving `DistanceDriveState` an async `init()`, all three control modules own their full setup internally. `execute_intent_setup` has no real work. The seam had one real adapter and two dead ones — a hypothetical seam, not a real one.

## Considered options

**Make the descriptor system real.** Move sensor start from `init()` into `execute_intent_setup` for all three intents. Dispatch owns sensor lifecycle. **Rejected** — adds indirection without leverage. The dispatch gains no new capability (it can't substitute sensors, can't test them independently), and the one-caller-per-descriptor ratio means the seam is hypothetical. Complexity moves from init functions to a central match statement.

**Delete IntentSetup, keep IntentTeardown.** `IntentTeardown` is real — all three variants are executed by `execute_intent_teardown` on completion or interrupt, and the teardown logic (stop encoder, stop IMU, zero motors) benefits from centralisation since it runs from both the completion and interrupt paths. **Chosen** — setup is init's responsibility; teardown is dispatch's. Teardown remains a real seam with two callers (completion and interrupt).

## Consequences

- `IntentSetup` enum and `execute_intent_setup` are deleted.
- `IntentTeardown` and `execute_intent_teardown` remain unchanged.
- `BrakeCoastState::init()` becomes async and calls `start_encoder_sampling()` internally.
- `DistanceDriveState::init()` becomes async and owns sensor start, reference capture, and initial motor command. IMU startup + DMP stabilisation is handled by the dispatch gate (`ensure_imu_ready`).
- `RotationState::init()` unchanged — already async, already owns setup.
- `handle_drive_distance` in dispatch shrinks to a thin router matching `handle_rotate_exact`.
- The dispatch is now genuinely thin: route commands, execute teardown on completion/interrupt, manage epoch.

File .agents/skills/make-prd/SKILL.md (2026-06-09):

---
name: make-prd
description: make a product requirement dosument out of a grilling session
disable-model-invocation: false
---

This skill takes the current conversation context and codebase understanding and produces a PRD. Do NOT interview the user — just synthesize what you already know.

The issue tracker and triage label vocabulary should have been provided to you — run `/setup-matt-pocock-skills` if not.

## Process

1. Explore the repo to understand the current state of the codebase, if you haven't already. Use the project's domain glossary vocabulary throughout the PRD, and respect any ADRs in the area you're touching.

2. Sketch out the major modules you will need to build or modify to complete the implementation. Actively look for opportunities to extract deep modules that can be tested in isolation.

A deep module (as opposed to a shallow module) is one which encapsulates a lot of functionality in a simple, testable interface which rarely changes.

Check with the user that these modules match their expectations. Check with the user which modules they want tests written for.

3. Write the PRD using the template below, then publish it to the project issue tracker. Apply the `needs-triage` triage label so it enters the normal triage flow.

<prd-template>

## Problem Statement

The problem that the user is facing, from the user's perspective.

## Solution

The solution to the problem, from the user's perspective.

## User Stories

A LONG, numbered list of user stories. Each user story should be in the format of:

1. As an <actor>, I want a <feature>, so that <benefit>

<user-story-example>
1. As a mobile bank customer, I want to see balance on my accounts, so that I can make better informed decisions about my spending
</user-story-example>

This list of user stories should be extremely extensive and cover all aspects of the feature.

## Implementation Decisions

A list of implementation decisions that were made. This can include:

- The modules that will be built/modified
- The interfaces of those modules that will be modified
- Technical clarifications from the developer
- Architectural decisions
- Schema changes
- API contracts
- Specific interactions

Do NOT include specific file paths or code snippets. They may end up being outdated very quickly.

## Testing Decisions

A list of testing decisions that were made. Include:

- A description of what makes a good test (only test external behavior, not implementation details)
- Which modules will be tested
- Prior art for the tests (i.e. similar types of tests in the codebase)

## Out of Scope

A description of the things that are out of scope for this PRD.

## Further Notes

Any further notes about the feature.

</prd-template>

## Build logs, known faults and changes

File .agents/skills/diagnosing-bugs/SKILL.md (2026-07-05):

---
name: diagnosing-bugs
description: Disciplined diagnosis loop for hard bugs. Use when the user reports a defect, says "diagnose"/"debug this", describes something broken/throwing/failing/slow, or wants to investigate a misbehavior. Grounds investigation in ADRs and CONTEXT.md so the gap between intended design and observed behavior is always clear. Handles code bugs, sensor-drift bugs, event-misfire bugs, and physical-world noise through a dedicated HITL iteration loop.
---

# Diagnosing Bugs

A disciplined loop for hard bugs. **Skip phases only when explicitly justified.** If you catch yourself jumping ahead (fixing before understanding, hypothesising before tracing), stop — that's the exact failure mode this skill prevents.

The skill works in two tracks:

- **Track A — Static analysis first.** Read the code, trace the data flow, find where it diverges from the aligned intended behaviour. Many bugs are visible in the code once you know what you're looking for. If found, grill fix avenues and execute.
- **Track B — Dynamic debugging.** If static analysis doesn't reveal the root cause (code looks correct, bug is in sensor data / timing / events / hardware / physical-world noise), fall into a feedback loop — HITL for embedded systems, automated loops for server-side code.

---

## Phase 0 — Align on the gap (system understanding via grilling + code reading)

This is the foundation. Before diagnosing, align on **what is happening** vs **what should be happening**, and achieve enough system understanding to trace the relevant code paths. Don't skip this.

### 0.1 Capture the symptom

Ask the user, one question at a time:

1. **What did you observe?** Get the raw symptom — error message, wrong output, crash, hang, slow timing, unexpected physical behaviour. Be concrete. "It's broken" is not a symptom; "the robot leg extends past 90° when given a 45° command" is. "The IMU reports heading drift of 15° over 30 seconds" is.

2. **What did you expect?** Get the intended behaviour in the same concrete terms. "The leg should stop at the commanded angle."

3. **What triggers it?** Steps, inputs, configuration, timing, environment. Even a 1-in-100 flake is useful.

4. **When was it last working?** Pin the regression window if known. Otherwise note as a data gap.

5. **What's the blast radius?** Safety hazard? Data loss? Cosmetic?

### 0.2 Read the design docs

Read `CONTEXT.md` and any ADRs in `docs/adr/` relevant to the symptom's area. For each relevant ADR, ask:

- "ADR-NNNN defines X behaviour — is this bug a violation of that decision?"
- "Does the ADR specify expected ranges, timing constraints, or event ordering that this symptom violates?"

If the user describes intended behaviour that **contradicts** an existing ADR, flag it immediately: "ADR-0004 says the leg controller should clip commands to 0–90°, but you're saying it should reject commands outside that range — which is the intended behaviour?"

**If the user and the ADRs agree but the code disagrees, you have a clear bug — the code is violating the design.**

**If the user, the ADRs, and the code all disagree with each other, you have a design drift problem — pause and resolve which is authoritative.**

### 0.3 Read the code to achieve system understanding

Now read the code in the affected area. Do NOT try to find the bug yet — just build a mental model. The goal is to understand:

- **The data flow:** Where does the relevant data originate? What transforms does it pass through? Where is it consumed to produce the output/behaviour that's misbehaving?
- **The module structure:** What modules/systems are involved? What are their interfaces and seams? Use the architecture vocabulary: modules, interfaces, seams, adapters.
- **The control flow:** What triggers the behaviour? Is it event-driven, periodic, request-response? What are the key decision points?
- **The coupling points:** Where does the code cross a seam into external systems (sensors, actuators, other tasks, hardware registers)?

Read broadly enough to trace the full path from trigger to symptom. Use `grep` to find the relevant entry points, then trace forward.

**Confirm your understanding with the user:**

> "Here's my understanding of the data flow: the leg angle command originates in `motion_planner.rs` → passes through `leg_controller.rs` which applies PID → reaches `motor_driver.rs` which converts to PWM. The symptom is at the motor output. I'll now trace this path looking for where the 45° command becomes 90°. Does this match your mental model of the system?"

If the user corrects your understanding, adjust and re-confirm. Do not proceed until system understanding is shared.

### 0.4 Write the gap statement

Before proceeding, capture the alignment:

> **Observed:** `<concrete symptom>`  
> **Expected:** `<concrete intended behaviour per ADRs / user>`  
> **Gap:** `<one-line summary of the delta>`

Show it to the user for confirmation. Do not proceed until agreed.

---

## Phase 1 — Static code analysis: trace the divergence

Now, with system understanding and an aligned target, trace the code to find where it diverges from intended behaviour. This is the **first diagnosis pass** — many bugs are visible in the code once you know the data flow and the expected outcome.

### 1.1 Trace the data flow against the expected behaviour

Starting from the trigger, walk the code path step by step. At each step, ask:

- **What value should be here?** (per the aligned expected behaviour from Phase 0)
- **What value will actually be produced?** (per the code)
- **Do they match?**

Look for:

- **Off-by-one errors** — loops, bounds, indices
- **Wrong units or coordinate frames** — degrees vs radians, global vs local, milliseconds vs microseconds
- **Missing transformations** — a calibration step, a filter, a bounds check that should exist
- **Inverted logic** — `>` instead of `>=`, `&&` instead of `||`
- **Stale or wrong constants** — hardcoded values that don't match the ADR or spec
- **Ordering violations** — operation A happens before operation B but should happen after
- **Missing error handling** — a `Result` that's silently discarded, a sensor read that can fail
- **Type coercion issues** — silent truncation, integer division where float is needed, sign mismatch
- **Lock or synchronization issues** — shared state accessed without the documented lock order
- **ADR violations** — code that directly contradicts a documented architectural decision

### 1.2 If a root cause is found → grill fix avenues

If the trace reveals a clear divergence point — a specific line or block where the code produces something different from what's expected — you have identified a **candidate root cause**.

**Do NOT apply the fix yet.** First, present the finding and grill fix avenues:

> "I traced the angle command from `motion_planner.rs:42` through the PID controller. The divergence is at `leg_controller.rs:156` — the PID output is `angle_cmd + pid_output` but it should be `pid_output` (the command is already in the setpoint, adding it again doubles the output for positive commands). This explains why a 45° command becomes 90°.
>
> Fix avenue A: Remove the `angle_cmd +` from line 156. This is a one-line change, but it assumes the PID setpoint is set correctly upstream — I need to verify.
>
> Fix avenue B: Set the PID setpoint to 0 and keep the feedforward addition. More explicit about the separation of feedforward and feedback paths, but touches more code.
>
> Which avenue do you want to explore? Or do you see a different fix?"

**Grill each avenue**, one at a time, using the grilling discipline:

- Walk down the implications of each avenue: what else changes? What tests would need updating? Does it create a regression risk elsewhere?
- If an avenue contradicts an ADR, flag it: "Avenue A means the PID controller no longer sees the commanded angle — but ADR-0007 says the controller must monitor the command for safety limits. That suggests Avenue B."
- If an avenue introduces a new seam or abstraction, note it for post-mortem.

**Execute the chosen fix** — apply it, verify it addresses the gap, then jump to Phase 5 (regression test + cleanup + post-mortem). Skip the dynamic debugging phases — the bug was found through static analysis.

### 1.3 If the avenue proves non-viable during execution

If you start executing a fix avenue and discover it doesn't work (e.g., the underlying assumption was wrong, it causes a regression, it doesn't fix the symptom), report back:

> "Avenue A doesn't fix it — removing the feedforward addition makes the leg not move at all. The PID isn't configured as a full controller; it's only providing damping on top of the feedforward. Let me go back to the code trace and re-check my assumptions. Or do you want to try Avenue B?"

If all avenues from the initial root cause are exhausted without fixing the symptom, the root cause may be wrong. Fall through to Phase 2 — the code trace didn't find the true cause, so dynamic debugging is needed.

### 1.4 If no root cause is found via static analysis

If you complete the code trace and the code appears correct — every step produces what it should produce, the logic matches the ADRs, the units and coordinate frames are consistent — then the bug is likely external to the code. State this explicitly:

> "I've traced the full path from command to motor output. The code is correct by design — every transformation is as specified, every bounds check is in place. The 90° output should be impossible for a 45° input. This suggests the bug's source is external: sensor data feeding the setpoint, a timing issue, a hardware fault, or an event misfire. I'll switch to dynamic debugging."

Proceed to Phase 2.

---

## Phase 2 — Dynamic debugging: build a feedback loop

The bug wasn't found in the code — it manifests at runtime. Build a feedback loop to observe it.

**This is the skill.** If you have a **tight** pass/fail signal for the bug, you will find the cause. If you don't, no amount of staring will save you.

### Ways to construct one — try them in roughly this order

1. **Failing test** at whatever seam reaches the bug — unit, integration, e2e.
2. **CLI invocation** with a fixture input, diffing stdout against a known-good snapshot.
3. **Replay a captured trace.** Save a real payload / event log to disk; replay it through the code path in isolation.
4. **Throwaway harness.** Minimal subset of the system that exercises the bug code path.
5. **Property / fuzz loop.** 1000 random inputs, look for the failure mode.
6. **Differential loop.** Old-version vs new-version, diff outputs.
7. **HITL log-driven loop.** See Phase 2b. For embedded/physical bugs where the agent can't run the system unattended.

### Tighten the loop

Can you make it faster? Sharper? More deterministic? A 2-second deterministic loop is a superpower; a 30-second flaky one is barely useful.

### Non-deterministic bugs

Goal: higher reproduction rate. Loop 100×, parallelise, add stress, narrow timing windows. 50%-flake is debuggable; 1% is not.

### Completion criterion

Phase 2 is done when you can name **one command or procedure** that you have **already run** (paste invocation + output), that is:

- [ ] **Red-capable** — drives the actual bug path and asserts the user's exact symptom from Phase 0.4
- [ ] **Deterministic** (or high repro rate)
- [ ] **Fast** — seconds, not minutes
- [ ] **Agent-runnable** (for HITL: agent drives procedure, human is the instrument)

---

## Phase 2b — HITL log-driven loop (for data/signal/event/hardware bugs)

When the bug source is outside the code (sensor data, physical events, hardware, timing, environment), the feedback loop involves a human running the system and reporting back.

### 2b.1 Instrument the data flow

Add targeted `defmt!` (or equivalent) instrumentation at the **boundaries** of the suspected data flow:

1. **Source** — right after sensor read, ADC conversion, event capture. Log the raw value.
2. **Transform** — after calibration, filtering, coordinate transform. Log the intermediate.
3. **Decision** — just before the code acts on the value (threshold check, control output).
4. **Effect** — the actuator command, state transition, or output.

Tag every log with a session-unique prefix, e.g. `[HITL-a4f2]`. Cleanup is a single grep.

Example for an IMU heading drift bug:

```rust
defmt::debug!("[HITL-a4f2] raw_gyro_z={} dps", raw_gyro_z);
defmt::debug!("[HITL-a4f2] filtered_gyro_z={} dps", filtered_gyro_z);
defmt::debug!("[HITL-a4f2] heading_deg={}", heading_deg);
defmt::debug!("[HITL-a4f2] motor_cmd_yaw={}", motor_cmd_yaw);
```

**Keep instrumentation minimal** — instrument only the data path directly related to the symptom.

### 2b.2 Define the HITL procedure

Give the user a concrete, reproducible, bounded procedure:

> **HITL procedure #1 — IMU drift observation**
>
> 1. Flash firmware with `[HITL-a4f2]` instrumentation.
> 2. Place robot on a level surface, stationary, powered on.
> 3. Connect debug probe and log: `probe-rs run --chip RP2350 | tee hitl-1.log`
> 4. Let it run for 60 seconds. Do not touch the robot.
> 5. Stop logging. Send me `hitl-1.log`.

### 2b.3 Analyze the logs

When the user returns logs, analyze them against the design tree:

1. **Does the data flow match the ADR's expected path?**
2. **Are values within expected ranges?** Flag any value outside spec from ADRs.
3. **Is the data flow complete?** Any missing transforms, skipped filters, zero-where-should-be-nonzero?
4. **Where is the divergence point?** Find the exact log line where values go from correct to incorrect.

Report findings to the user:

> "Log analysis: raw gyro reads 0.0 dps (correct for stationary), filtered gyro reads 0.0 dps (correct), but heading_deg increases at 0.5°/s. The divergence is between filtered_gyro_z and heading_deg. The integration step is accumulating an offset."

### 2b.4 Iterate — narrow the instrumentation

Add more targeted instrumentation around the suspect area. Remove instrumentation from paths confirmed correct. Each iteration narrows the suspect region and adds a concrete prediction. Repeat until root cause is isolated.

### 2b.5 Stop conditions for HITL

- **Root cause isolated in code** → proceed to Phase 3 (hypothesise), then Phase 5 (fix)
- **Root cause is external** (sensor fault, mechanical, EMI, power) → document with log evidence. Ask: "Should we add a code-level defense (sanity check, timeout, validation gate)? Should the ADR specify one?"
- **Cannot isolate after 5 iterations** → reassess. Consider higher-frequency logging, oscilloscope/protocol analyzer, reclassifying the source.

---

## Phase 3 — Hypothesise

Generate **3–5 ranked hypotheses** before testing any of them. Each hypothesis must be **falsifiable**:

> "If `<X>` is the cause, then `<changing Y>` will make the bug disappear / `<changing Z>` will make it worse."

If you cannot state the prediction, discard or sharpen the hypothesis.

### Grill the user on the ranking

Show the ranked list. State your reasoning. **Ask one question per hypothesis, waiting for feedback.** The user's domain knowledge may re-rank instantly.

If the user is AFK, proceed with your ranking — note the lack of domain confirmation.

---

## Phase 4 — Instrument

Each probe maps to a specific prediction from Phase 3. **Change one variable at a time.**

Tool preference: debugger/REPL first, targeted logs second. Never "log everything and grep."

Tag every debug log with a unique prefix, e.g. `[DEBUG-a4f2]`.

As probes narrow the cause, surface findings to the user: "`[DEBUG-a4f2]` confirms the divergence is inside the controller module. Align with your understanding?"

---

## Phase 5 — Fix + regression test + cleanup + post-mortem

### 5.1 Regression test

Write the regression test **before the fix** — but only if there is a **correct seam** for it (exercises the real bug pattern). If no correct seam exists, note it — the architecture is preventing the bug from being locked down (flag for post-mortem).

For HITL bugs: the regression test injects the bad data pattern discovered in Phase 2b. No hardware needed.

### 5.2 Apply the fix

1. Turn the minimised repro into a failing test at the correct seam.
2. Watch it fail.
3. Apply the fix.
4. Watch it pass.
5. Re-run the Phase 2 feedback loop against the original scenario.

### 5.3 Cleanup

- [ ] Original repro no longer reproduces
- [ ] Regression test passes (or absence of seam is documented)
- [ ] All `[DEBUG-...]` and `[HITL-...]` instrumentation removed (`grep` the prefix)
- [ ] Throwaway prototypes deleted
- [ ] Correct hypothesis stated in commit/PR message

### 5.4 Grill with docs — the post-mortem

Walk through these questions with the user, one at a time. Use the `domain-modeling` discipline for docs.

1. **What would have prevented this bug?** If architectural, hand off to `/improve-codebase-architecture`. If a missing constraint, offer an ADR.

2. **Did this bug reveal a missing domain concept?** If terminology was inconsistent, sharpen it in CONTEXT.md.

3. **Did this bug contradict an ADR?** If the code violated an ADR, note it. If the ADR was wrong, offer to supersede it.

4. **Did we make an architectural trade-off?** If the fix introduces a new seam or changes coupling, consider an ADR.

5. **Is there a pattern?** Nth bug in same module or same class? Flag it.

6. **For hardware/external root causes:** Did we add a code-level defense? Should it be encoded as a defensive-design ADR?

**End with:** "The gap from Phase 0.4 is now closed. Observed = expected. Anything else you want to investigate?"

---

## Reference — when to use this vs other skills

| Situation | Use |
|---|---|
| "X is broken, investigate" | `diagnosing-bugs` (this skill) |
| "The sensor data looks wrong but code seems fine" | `diagnosing-bugs` → Phase 2b HITL loop |
| "It works sometimes but not others" | `diagnosing-bugs` → likely event/timing, Phase 2b |
| "Review my code for issues" | `code-review` |
| "Is this codebase well-designed?" | `improve-codebase-architecture` |
| "Stress-test my plan before I build" | `grill-me` or `grill-with-docs` |

This skill hands off to `domain-modeling` (for CONTEXT.md/ADR updates) and `improve-codebase-architecture` (for post-mortem architectural findings). It does not replace them.

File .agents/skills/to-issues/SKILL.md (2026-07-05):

---
name: to-issues
description: Break a plan, spec, or PRD into independently-grabbable implementation slices written as markdown files in docs/issues/ using tracer-bullet vertical slices.
disable-model-invocation: true
---

# To Issues

Break a plan into independently-grabbable implementation slices using vertical slices (tracer bullets). Each slice becomes a markdown file in `docs/issues/`.

## File structure

```
docs/
├── prd/
│   └── mobile-check-deposit.md
├── issues/
│   ├── 0001-add-check-image-capture.md
│   ├── 0002-submit-deposit-to-backend.md
│   └── 0003-display-deposit-status.md
└── adr/
```

Create `docs/issues/` lazily — only when the first issue is written.

## Process

### 1. Gather context

Work from whatever is already in the conversation context. If the user references a PRD file, read it and use its contents.

### 2. Explore the codebase (optional)

If you have not already explored the codebase, do so to understand the current state of the code. Issue titles and descriptions should use the project's domain glossary vocabulary, and respect ADRs in the area you're touching.

Look for opportunities to prefactor the code to make the implementation easier. "Make the change easy, then make the easy change."

### 3. Draft vertical slices

Break the plan into **tracer bullet** slices. Each slice is a thin vertical cut that cuts through ALL integration layers end-to-end, NOT a horizontal slice of one layer.

<vertical-slice-rules>

- Each slice delivers a narrow but COMPLETE path through every layer (schema, API, UI, tests)
- A completed slice is demoable or verifiable on its own
- Any prefactoring should be done first

</vertical-slice-rules>

### 4. Quiz the user

Present the proposed breakdown as a numbered list. For each slice, show:

- **Title**: short descriptive name
- **Blocked by**: which other slices (if any) must complete first
- **User stories covered**: which user stories this addresses (if the source material has them)

Ask the user:

- Does the granularity feel right? (too coarse / too fine)
- Are the dependency relationships correct?
- Should any slices be merged or split further?

Iterate until the user approves the breakdown.

### 5. Write the slices to docs/issues/

For each approved slice, write a markdown file to `docs/issues/`. Use sequential numbering: `0001-slug.md`, `0002-slug.md`, etc. Scan the directory for the highest existing number and increment. Derive the slug from the slice title: lowercase, hyphenated.

Write files in dependency order (blockers first) so you can reference real filenames in the "Blocked by" field.

<issue-template>
## Parent

A reference to the source PRD file (e.g. `docs/prd/mobile-check-deposit.md`), if one exists. Otherwise omit this section.

## What to build

A concise description of this vertical slice. Describe the end-to-end behavior, not layer-by-layer implementation.

Avoid specific file paths or code snippets — they go stale fast. Exception: if a prototype produced a snippet that encodes a decision more precisely than prose can (state machine, reducer, schema, type shape), inline it here and note briefly that it came from a prototype. Trim to the decision-rich parts — not a working demo, just the important bits.

## Acceptance criteria

- [ ] Criterion 1
- [ ] Criterion 2
- [ ] Criterion 3

## Blocked by

- `0001-other-slice.md` (or link to the blocking file)

Or "None - can start immediately" if no blockers.

</issue-template>

Do NOT modify any parent PRD file.

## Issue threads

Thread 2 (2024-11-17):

detection is too narrow and flat angles prohibit detection

1-rafael-1, 2024-11-17:
the bot hits obstacles with its tracks because detection has no sweep and only 15° angle. Need a better suited sensor or a second hc-sr04 or mount the hc-sr04 on something that can sweep...

1-rafael-1, 2024-11-19:
> try to add the sensor on an servo motor and rotate it time and time again(just like a small Lidar sensor)

Yes that is one option I can follow. I believe I will maybe do this to explore how spatial awareness and pathfinding works. For starters I will try a IR sensor that has 35° angle. That should be better for all sorts of obstacles because sound will bounce but light will scatter and so this should work better.

XiaoPengYouCode, 2024-11-19:
how about try to use a cheap off-the-shelf LiDAR, it can map environment srounded into a 2D point-cloud-data, and you can use it to build automatic cruise.

XiaoPengYouCode, 2024-11-19:
> how about try to use a cheap off-the-shelf LiDAR, it can map environment srounded into a 2D point-cloud-data, and you can use it to build automatic cruise.

that's more cool maybe for your kids❤️

Closed 2025-01-11.

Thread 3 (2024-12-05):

thre is no speed control and that way no precicse straight line movement or accurate turning -> add encoders

1-rafael-1, 2024-12-05:
The two dc motors are very cheap and the printed chassis and cog wheel and tracks combined do not allow accurate control of how we move, Step one is to replace the motors with ones with better transmission, more torque and what is most important: an encoder.

Need to add the encoders and hook them into a feedback loop so they can
- determine each motors turning speed, and align both motors to match
- enable accurate turning instructions, like "turn 25 degrees left", to achieve that I will need to calibrate the thing

Both things need not be perfect in step 1 I think, because I will add a sensor for motion and heading that we can later hook into the correction... somehow...

Closed 2025-01-11.

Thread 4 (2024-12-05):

there is no sensor to correct heading

1-rafael-1, 2024-12-05:
even with encoders we will still not truly know if we move straight or turn as we wanted, because tracks may slip, the entire robot may get re-oriented by an obstacle, ... that sort of thing.

So next up: add an MPU-6050 sensor IC to obtain data. Then hook that data into the correction of motor speed.
Probably also add calibration at startup, as far as i read the IC will want that to work properly later. So:

Spawn a task that signals "I am calibrating", calibrates and then signals "I am done calibrating" and enters its acquisition loop.
Make the drive task aware that it should await end of calibration before entering its execution loop.

Closed 2025-01-11.

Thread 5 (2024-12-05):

find something to do for improved driving accuracy

1-rafael-1, 2024-12-05:
once we learned how to drive with precision, we need some way to make use of it. There will be a spare HC-SR04... and the basement stash should hold a 9g servo.

So:
- make a poor mans lidar out of a servo and the sensor
- rig that on the bot
- then implement some task that sweeps and records distance data in its field of view
- then implement a way to hold that data and .... yeah what then? Maybe determine the most straight line from where we are that is farthest away from all obstacles, turn into that direction and drive for 2m. Repeat. That way we use the data and demonstrate we can drive smewhere intentionally.

Closed 2025-01-11.

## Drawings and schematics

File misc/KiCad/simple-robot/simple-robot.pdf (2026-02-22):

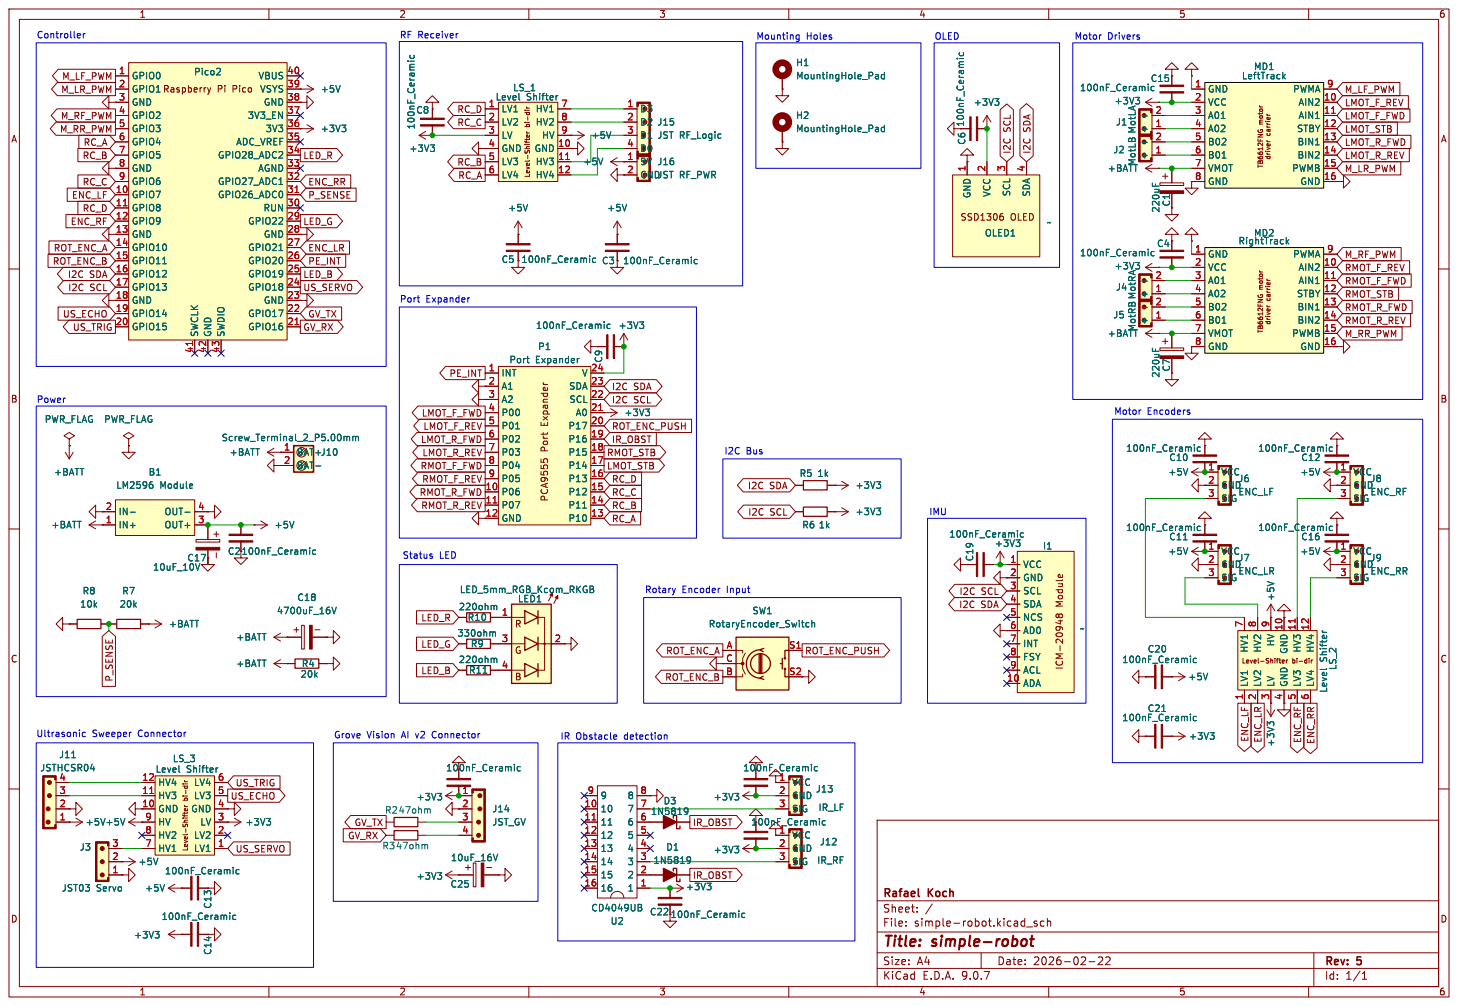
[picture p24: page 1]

driver carrier GND 1 VCC 2 A01 3 A02 4 B02 5 B01 6 VMOT 7 GND 8 PWMA 9 AIN2 10 AIN1 11 STBY 12 BIN1 13 BIN2 14 PWMB 15 GND 16 MD1

driver carrier GND 1 VCC 2 A01 3 A02 4 B02 5 B01 6 VMOT 7 GND 8 PWMA 9 AIN2 10 AIN1 11 STBY 12 BIN1 13 BIN2 14 PWMB 15 GND 16 MD2 RightTrack C7 220uF

INT 7 FSY 8 ACL 9 ADA 10

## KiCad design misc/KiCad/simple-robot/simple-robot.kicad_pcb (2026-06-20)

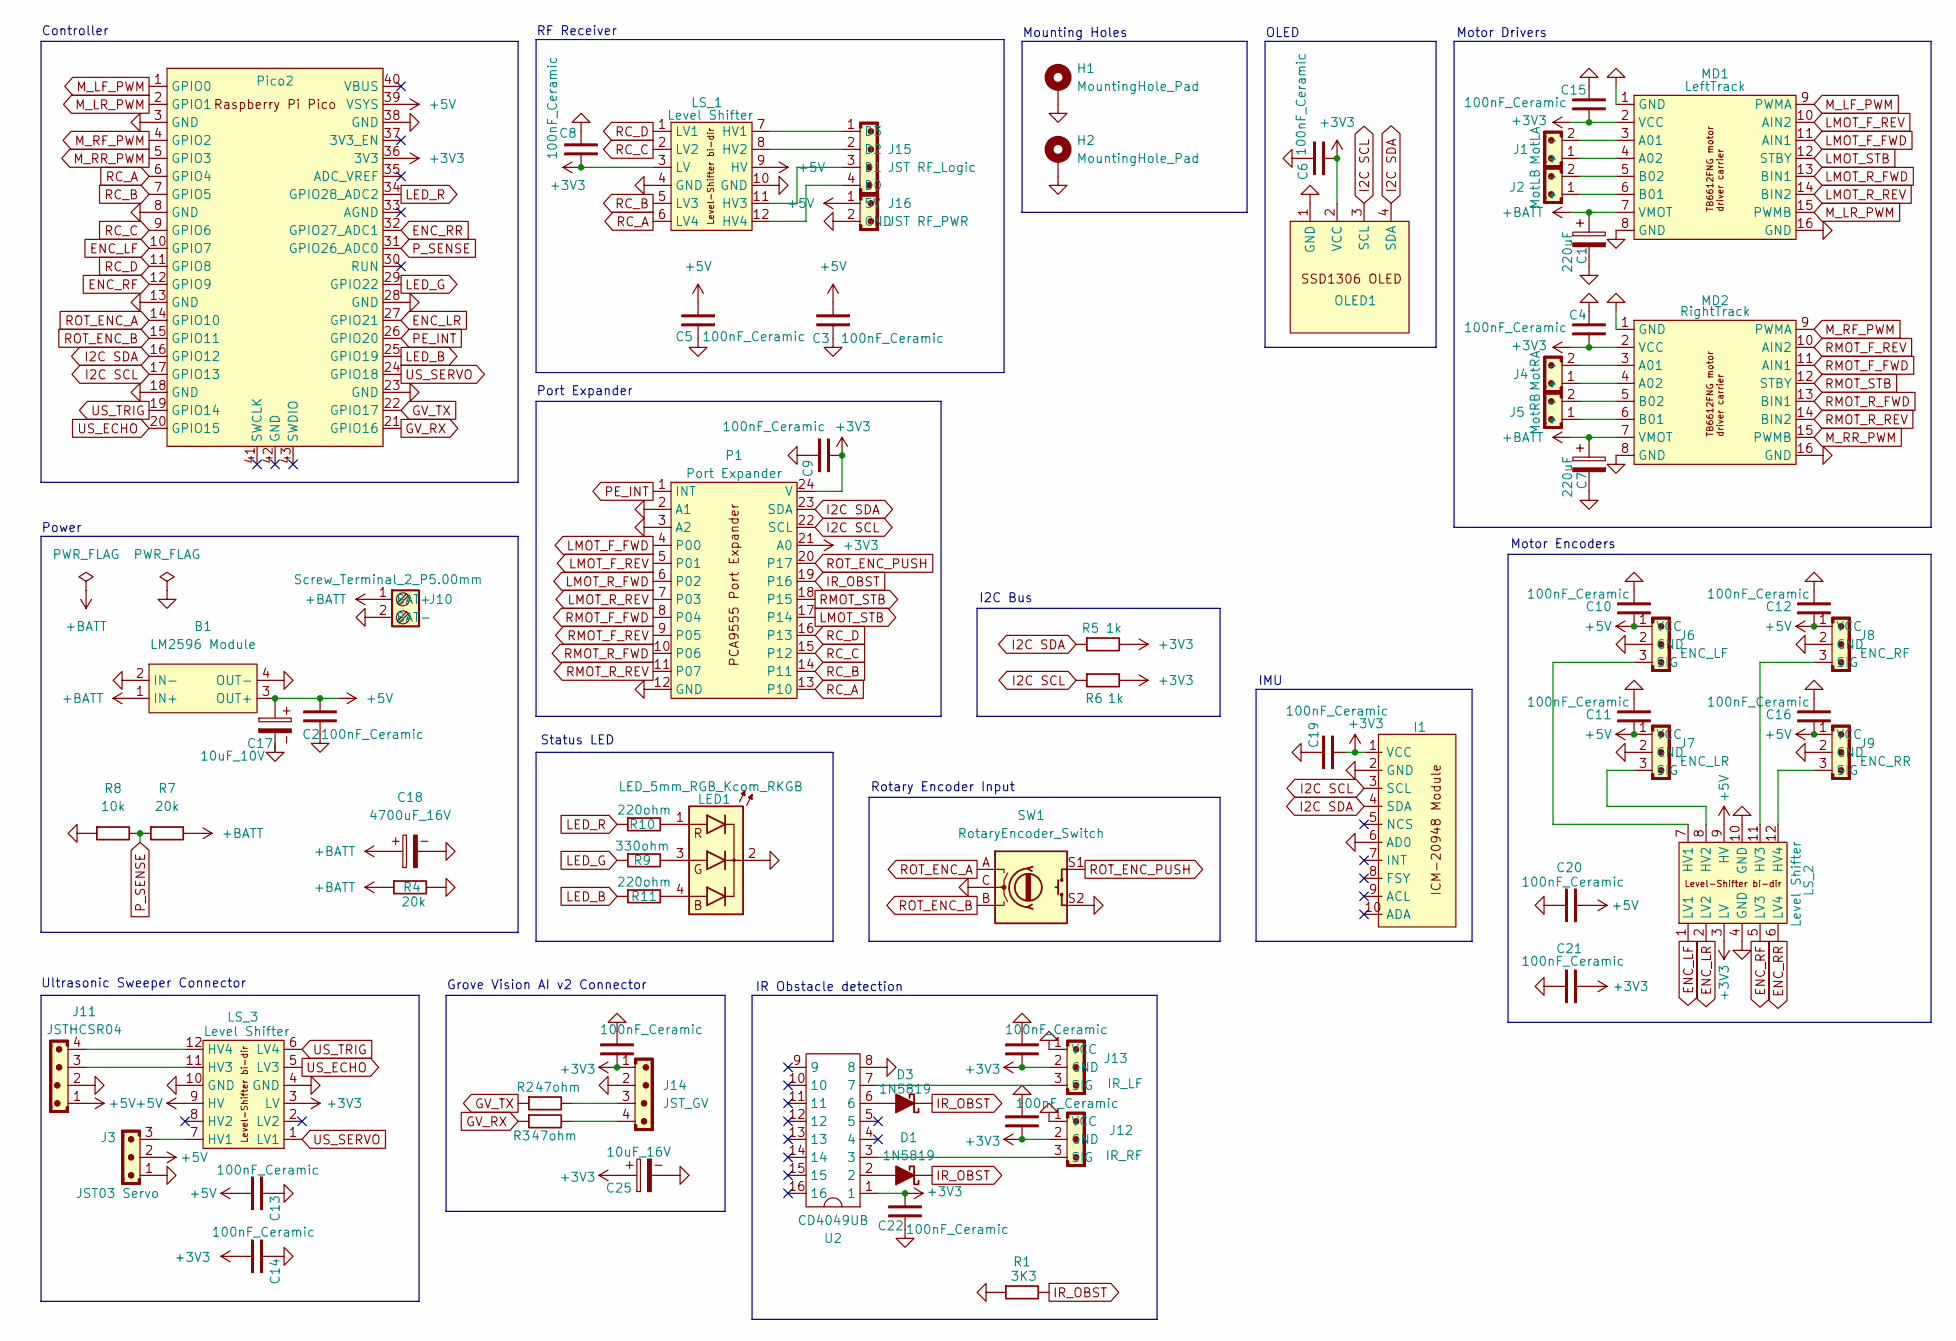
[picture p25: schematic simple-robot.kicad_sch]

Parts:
B1: LM2596 Module; LM2596_Module
C1, C7: 220uF; CP_Radial_D6.3mm_P2.50mm
C2, C3, C4, C5, C6, C8, C9, C10, C11, C12, C13, C14, C15, C16, C19, C20, C21, C22, C23, C24, C26: 100nF_Ceramic; C_Disc_D5.0mm_W2.5mm_P2.50mm
C17: 10uF_10V; CP_Radial_D6.3mm_P2.50mm
C18: 4700uF_16V; CP_Radial_D16.0mm_P7.50mm
C25: 10uF_16V; CP_Radial_D5.0mm_P2.00mm
D1, D3: 1N5819; D_DO-41_SOD81_P7.62mm_Horizontal
H1, H2: MountingHole_Pad; MountingHole_3.7mm_Pad_Via
I1: ICM-20948-module
J1: MotLA; JST_PH_B2B-PH-K_1x02_P2.00mm_Vertical
J2: MotLB; JST_PH_B2B-PH-K_1x02_P2.00mm_Vertical
J3: JST03 Servo; JST_EH_B3B-EH-A_1x03_P2.50mm_Vertical
J4: MotRA; JST_PH_B2B-PH-K_1x02_P2.00mm_Vertical
J5: MotRB; JST_PH_B2B-PH-K_1x02_P2.00mm_Vertical
J6: ENC_LF; JST_PH_B3B-PH-K_1x03_P2.00mm_Vertical
J7: ENC_LR; JST_PH_B3B-PH-K_1x03_P2.00mm_Vertical
J8: ENC_RF; JST_PH_B3B-PH-K_1x03_P2.00mm_Vertical
J9: ENC_RR; JST_PH_B3B-PH-K_1x03_P2.00mm_Vertical
J10: Screw_Terminal_2_P5.00mm; TerminalBlock_Phoenix_PT-1,5-2-5.0-H_1x02_P5.00mm_Horizontal
J11: JSTHCSR04; JST_EH_B4B-EH-A_1x04_P2.50mm_Vertical
J12: IR_RF; JST_PH_B3B-PH-K_1x03_P2.00mm_Vertical
J13: IR_LF; JST_PH_B3B-PH-K_1x03_P2.00mm_Vertical
J14: JST_GV; JST_EH_B4B-EH-A_1x04_P2.50mm_Vertical
J15: JST RF_Logic; JST_EH_B4B-EH-A_1x04_P2.50mm_Vertical
J16: JST RF_PWR; JST_EH_B2B-EH-A_1x02_P2.50mm_Vertical
LED1: LED_5mm_RGB_Kcom_RKGB; LED_D5.0mm-4_RGB_Wide_Pins
LS_1, LS_2, LS_3: Level Shifter; Level shifter 4 bi-dir
MD1: LeftTrack; TB6612FNG motor driver carrier
MD2: RightTrack; TB6612FNG motor driver carrier
OLED1: SSD1306
P1: Port Expander; PCA9555 Port Expander
R1: 3K3; R_Axial_DIN0207_L6.3mm_D2.5mm_P10.16mm_Horizontal
R2, R3: 47ohm; R_Axial_DIN0207_L6.3mm_D2.5mm_P10.16mm_Horizontal
R4, R7: 20k; R_Axial_DIN0207_L6.3mm_D2.5mm_P10.16mm_Horizontal
R5, R6: 1k; R_Axial_DIN0207_L6.3mm_D2.5mm_P10.16mm_Horizontal
R8: 10k; R_Axial_DIN0207_L6.3mm_D2.5mm_P10.16mm_Horizontal
R9: 330ohm; R_Axial_DIN0207_L6.3mm_D2.5mm_P10.16mm_Horizontal
R10, R11: 220ohm; R_Axial_DIN0207_L6.3mm_D2.5mm_P10.16mm_Horizontal
SW1: RotaryEncoder_Switch; RotaryEncoder_Alps_EC11E-Switch_Vertical_H20mm
U1: Pico2; raspberry_pi_pico_THT
U2: CD4049UB; DIP-16_W7.62mm_LongPads

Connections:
+3V3: C4.1, C6.2, C8.1, C9.2, C14.1, C15.1, C19.1, C21.2, C22.2, C23.1, C24.1, C25.1, C26.1, I1.1 (VCC), J12.2 (GND), J13.2 (GND), J14.1, LS_1.3 (LV), LS_2.3 (LV), LS_3.3 (LV), MD1.2 (VCC), MD2.2 (VCC), OLED1.2 (VCC), P1.21 (A0), P1.24 (V), R5.2, R6.2, U1.36 (3V3), U2.1
+5V: B1.3 (OUT+), C2.2, C3.1, C5.1, C10.1, C11.1, C12.1, C13.1, C16.1, C17.1, C20.2, J3.2, J6.1 (VCC), J7.1 (VCC), J8.1 (VCC), J9.1 (VCC), J11.1, J16.1 (5V), LS_1.9 (HV), LS_2.9 (HV), LS_3.9 (HV), U1.39 (VSYS)
+BATT: B1.1 (IN+), C1.1, C7.1, C18.1, J10.1 (BAT+), MD1.7 (VMOT), MD2.7 (VMOT), R4.1, R7.2
ENC_LF: LS_2.1 (LV1), U1.10 (GPIO7)
ENC_LR: LS_2.2 (LV2), U1.27 (GPIO21)
ENC_RF: LS_2.5 (LV3), U1.12 (GPIO9)
ENC_RR: LS_2.6 (LV4), U1.32 (GPIO27_ADC1)
GND: B1.2 (IN-), B1.4 (OUT-), C1.2, C2.1, C3.2, C4.2, C5.2, C6.1, C7.2, C8.2, C9.1, C10.2, C11.2, C12.2, C13.2, C14.2, C15.2, C16.2, C17.2, C18.2, C19.2, C20.1, C21.1, C22.1, C23.2, C24.2, C25.2, C26.2, H1.1, H2.1, I1.2 (GND), I1.6 (AD0), J3.1, J6.2 (GND), J7.2 (GND), J8.2 (GND), J9.2 (GND), J10.2 (BAT-), J11.2, J12.1 (VCC), J13.1 (VCC), J14.2, J16.2 (GND), LED1.2 (A), LS_1.4 (GND), LS_1.10 (GND), LS_2.4 (GND), LS_2.10 (GND), LS_3.4 (GND), LS_3.10 (GND), MD1.1 (GND), MD1.8 (GND), MD1.16 (GND), MD2.1 (GND), MD2.8 (GND), MD2.16 (GND), OLED1.1 (GND), P1.2 (A1), P1.3 (A2), P1.12 (GND), R1.1, R4.2, R8.1, SW1.C, SW1.S2, U1.3 (GND), U1.8 (GND), U1.13 (GND), U1.18 (GND), U1.23 (GND), U1.28 (GND), U1.38 (GND), U2.8
GV_RX: R3.1, U1.21 (GPIO16)
GV_TX: R2.1, U1.22 (GPIO17)
I2C SCL: I1.3 (SCL), OLED1.3 (SCL), P1.22 (SCL), R6.1, U1.17 (GPIO13)
I2C SDA: I1.4 (SDA), OLED1.4 (SDA), P1.23 (SDA), R5.1, U1.16 (GPIO12)
IR_OBST: D1.1 (K), D3.1 (K), P1.19 (P16), R1.2
LED_B: R11.1, U1.25 (GPIO19)
LED_G: R9.1, U1.29 (GPIO22)
LED_R: R10.1, U1.34 (GPIO28_ADC2)
LMOT_F_FWD: MD1.11 (AIN1), P1.4 (P00)
LMOT_F_REV: MD1.10 (AIN2), P1.5 (P01)
LMOT_R_FWD: MD1.13 (BIN1), P1.6 (P02)
LMOT_R_REV: MD1.14 (BIN2), P1.7 (P03)
LMOT_STB: MD1.12 (STBY), P1.17 (P14)
M_LF_PWM: MD1.9 (PWMA), U1.1 (GPIO0)
M_LR_PWM: MD1.15 (PWMB), U1.2 (GPIO1)
M_RF_PWM: MD2.9 (PWMA), U1.4 (GPIO2)
M_RR_PWM: MD2.15 (PWMB), U1.5 (GPIO3)
unnamed: D1.2 (A), U2.2
unnamed: D3.2 (A), U2.6
unnamed: J1.1 (+), MD1.4 (A02)
unnamed: J1.2 (-), MD1.3 (A01)
unnamed: J2.1 (+), MD1.6 (B01)
unnamed: J2.2 (-), MD1.5 (B02)
unnamed: J4.1 (+), MD2.4 (A02)
unnamed: J4.2 (-), MD2.3 (A01)
unnamed: J5.1 (+), MD2.6 (B01)
unnamed: J5.2 (-), MD2.5 (B02)
unnamed: J6.3 (SIG), LS_2.7 (HV1)
unnamed: J7.3 (SIG), LS_2.8 (HV2)
unnamed: J8.3 (SIG), LS_2.11 (HV3)
unnamed: J9.3 (SIG), LS_2.12 (HV4)
unnamed: J12.3 (SIG), U2.3
unnamed: J13.3 (SIG), U2.7
unnamed: J14.3, R2.2
unnamed: J14.4, R3.2
unnamed: J15.4 (D0), LS_1.12 (HV4)
unnamed: J15.3 (D1), LS_1.11 (HV3)
unnamed: J15.2 (D2), LS_1.8 (HV2)
unnamed: J15.1 (D3), LS_1.7 (HV1)
unnamed: LED1.4 (B), R11.2
unnamed: LED1.3 (G), R9.2
unnamed: LED1.1 (R), R10.2
unnamed: J3.3, LS_3.7 (HV1)
unnamed: J11.3, LS_3.11 (HV3)
unnamed: J11.4, LS_3.12 (HV4)
PE_INT: P1.1 (INT), U1.26 (GPIO20)
P_SENSE: R7.1, R8.2, U1.31 (GPIO26_ADC0)
RC_A: LS_1.6 (LV4), P1.13 (P10), U1.6 (GPIO4)
RC_B: LS_1.5 (LV3), P1.14 (P11), U1.7 (GPIO5)
RC_C: LS_1.2 (LV2), P1.15 (P12), U1.9 (GPIO6)
RC_D: LS_1.1 (LV1), P1.16 (P13), U1.11 (GPIO8)
RMOT_F_FWD: MD2.11 (AIN1), P1.8 (P04)
RMOT_F_REV: MD2.10 (AIN2), P1.9 (P05)
RMOT_R_FWD: MD2.13 (BIN1), P1.10 (P06)
RMOT_R_REV: MD2.14 (BIN2), P1.11 (P07)
RMOT_STB: MD2.12 (STBY), P1.18 (P15)
ROT_ENC_A: SW1.A, U1.14 (GPIO10)
ROT_ENC_B: SW1.B, U1.15 (GPIO11)
ROT_ENC_PUSH: P1.20 (P17), SW1.S1
US_SERVO: LS_3.1 (LV1), U1.24 (GPIO18)

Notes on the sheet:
IMU
Mounting Holes
Grove Vision AI v2 Connector
I2C Bus
Port Expander
Rotary Encoder Input
Motor Encoders
Ultrasonic Sweeper Connector
IR Obstacle detection
OLED
RF Receiver
Motor Drivers
Status LED
Controller
Power

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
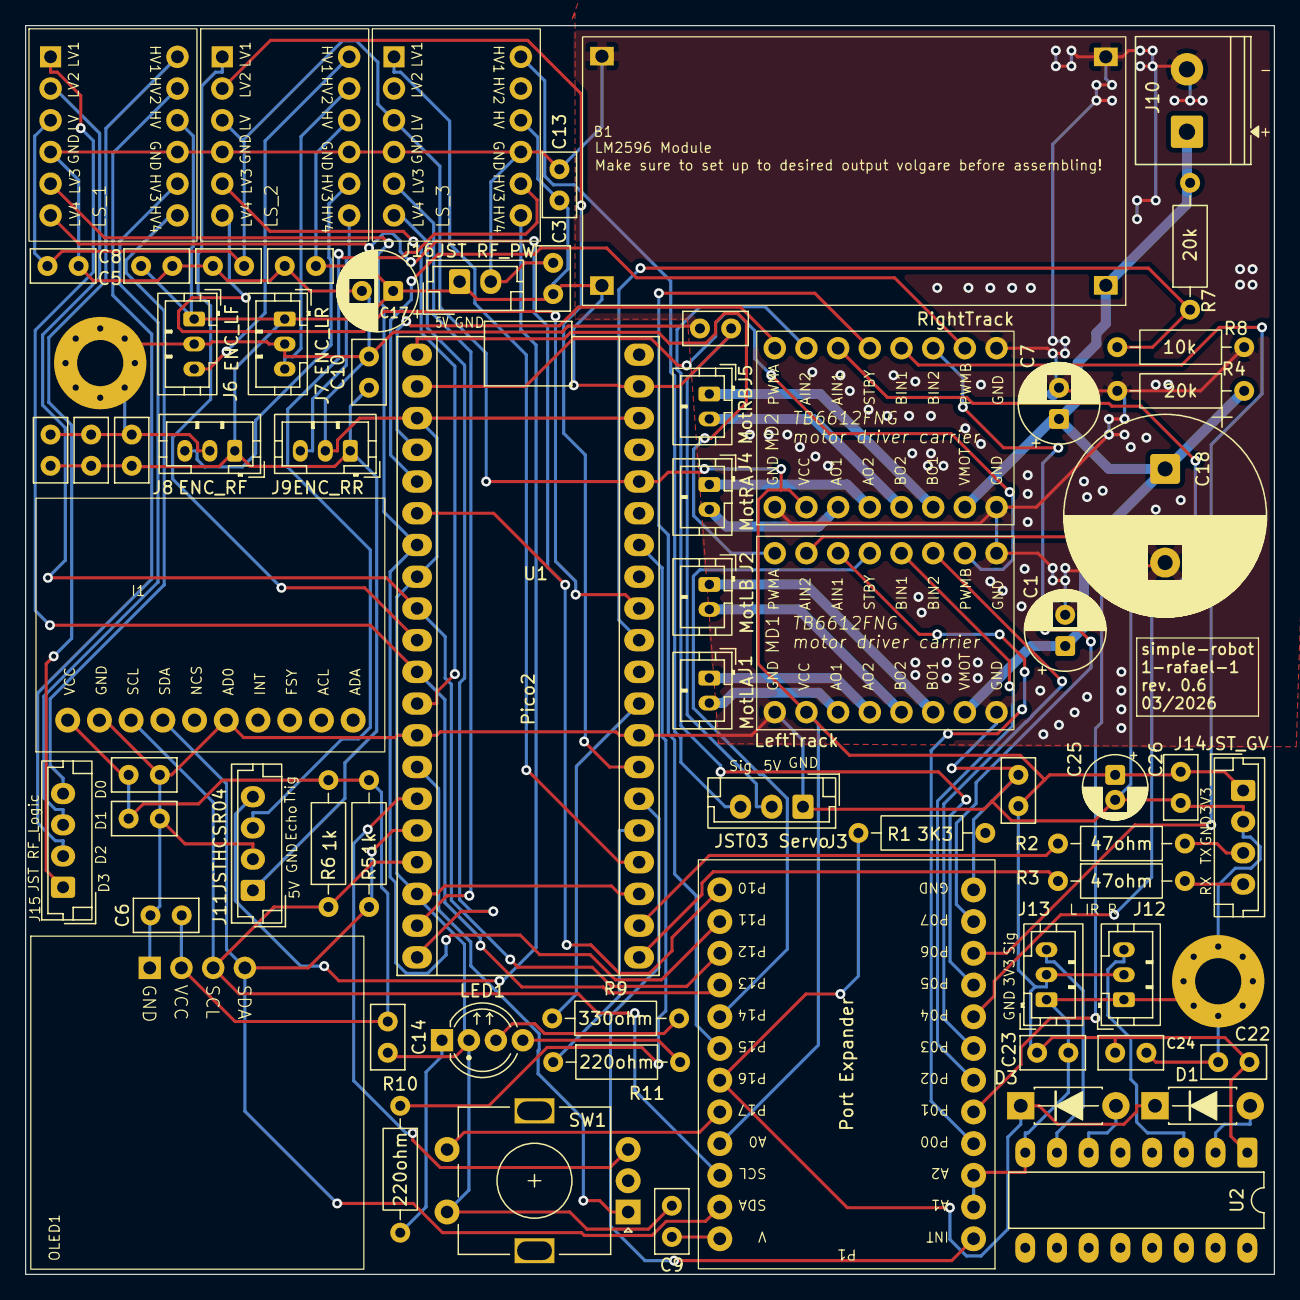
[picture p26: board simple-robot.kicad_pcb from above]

Board: 4 copper layers, 100.0 x 100.0 mm, 70 parts (0 on the bottom side), 70 nets.

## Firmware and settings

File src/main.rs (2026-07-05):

//! Robot firmware entry point
//!
//! Initializes system and spawns control tasks.

#![no_std]
#![no_main]

use defmt_rtt as _;
use embassy_executor::{Executor, Spawner};
use embassy_rp::{
    Peri,
    adc::{Adc, Channel, Config as AdcConfig, InterruptHandler as AdcInterruptHandler},
    bind_interrupts,
    block::ImageDef,
    config::Config,
    dma::InterruptHandler as DmaInterruptHandler,
    flash::{Async, Flash},
    gpio::{Input, Level, Output, Pull},
    i2c::{Config as I2cConfig, I2c, InterruptHandler as I2cInterruptHandler},
    multicore::{Stack, spawn_core1},
    peripherals::{DMA_CH0, I2C0, PIO0, PIO1},
    pio::{InterruptHandler as PioInterruptHandler, Pio},
    pio_programs::{
        pwm::{PioPwm, PioPwmProgram},
        rotary_encoder::{PioEncoder, PioEncoderProgram},
    },
    pwm::{InputMode, Pwm},
};
use embassy_sync::{blocking_mutex::raw::CriticalSectionRawMutex, mutex::Mutex};
use panic_probe as _;
use static_cell::StaticCell;

use crate::task::{autonomous_mode::init_autonomous_mode, testmode::init_testing, ui::init_ui};

/// Firmware image type for bootloader
#[unsafe(link_section = ".start_block")]
#[used]
pub static IMAGE_DEF: ImageDef = ImageDef::secure_exe();

/// System core modules
mod system;
/// Task implementations
mod task;

// Bind interrupts on global scope for convenience
bind_interrupts!(pub struct Irqs {
    I2C0_IRQ => I2cInterruptHandler<I2C0>;
    ADC_IRQ_FIFO => AdcInterruptHandler;
    PIO0_IRQ_0 => PioInterruptHandler<PIO0>;
    PIO1_IRQ_0 => PioInterruptHandler<PIO1>;
    DMA_IRQ_0 => DmaInterruptHandler<DMA_CH0>;
});

/// Motor driver peripheral pins (for new architecture with PCA9555)
/// Standby pins are now controlled via PCA9555 port expander (Port 1, bits 4-5)
struct MotorDriverPins {
    /// Left motor driver PWM slice
    lmot_pwm_slice: Peri<'static, embassy_rp::peripherals::PWM_SLICE0>,
    /// Left motor driver PWM channel A pin
    lmot_pwm_a: Peri<'static, embassy_rp::peripherals::PIN_0>,
    /// Left motor driver PWM channel B pin
    lmot_pwm_b: Peri<'static, embassy_rp::peripherals::PIN_1>,
    /// Right motor driver PWM slice
    rmot_pwm_slice: Peri<'static, embassy_rp::peripherals::PWM_SLICE1>,
    /// Right motor driver PWM channel A pin
    rmot_pwm_a: Peri<'static, embassy_rp::peripherals::PIN_2>,
    /// Right motor driver PWM channel B pin
    rmot_pwm_b: Peri<'static, embassy_rp::peripherals::PIN_3>,
    /// Left front motor encoder PWM slice
    encoder_left_front_slice: Peri<'static, embassy_rp::peripherals::PWM_SLICE3>,
    /// Left front motor encoder PWM pin
    encoder_left_front_pin: Peri<'static, embassy_rp::peripherals::PIN_7>,
    /// Left rear motor encoder PWM slice
    encoder_left_rear_slice: Peri<'static, embassy_rp::peripherals::PWM_SLICE2>,
    /// Left rear motor encoder PWM pin
    encoder_left_rear_pin: Peri<'static, embassy_rp::peripherals::PIN_21>,
    /// Right front motor encoder PWM slice
    encoder_right_front_slice: Peri<'static, embassy_rp::peripherals::PWM_SLICE4>,
    /// Right front motor encoder PWM pin
    encoder_right_front_pin: Peri<'static, embassy_rp::peripherals::PIN_9>,
    /// Right rear motor encoder PWM slice
    encoder_right_rear_slice: Peri<'static, embassy_rp::peripherals::PWM_SLICE5>,
    /// Right rear motor encoder PWM pin
    encoder_right_rear_pin: Peri<'static, embassy_rp::peripherals::PIN_27>,
}

/// RGB LED indicator pins
struct RgbLedPins {
    /// Red channel pin
    red: Peri<'static, embassy_rp::peripherals::PIN_28>,
    /// Green channel pin
    green: Peri<'static, embassy_rp::peripherals::PIN_22>,
    /// Blue channel pin
    blue: Peri<'static, embassy_rp::peripherals::PIN_19>,
}

/// EC11 rotary encoder pins
///
/// Note: Button pin is connected to the port expander and handled there
struct Ec11Pins {
    /// Pin A
    a: Peri<'static, embassy_rp::peripherals::PIN_10>,
    /// Pin B
    b: Peri<'static, embassy_rp::peripherals::PIN_11>,
}

/// RC Control button pins
struct RCButtonPins {
    /// Button A pin
    a: Peri<'static, embassy_rp::peripherals::PIN_4>,
    /// Button B pin
    b: Peri<'static, embassy_rp::peripherals::PIN_5>,
    /// Button C pin
    c: Peri<'static, embassy_rp::peripherals::PIN_6>,
    /// Button D pin
    d: Peri<'static, embassy_rp::peripherals::PIN_8>,
}

/// Grove Vision AI v2 module UART pins
#[allow(dead_code)] // planned for future use
struct GroveVisionUartPins {
    /// UART TX pin
    tx: Peri<'static, embassy_rp::peripherals::PIN_16>,
    /// UART RX pin
    rx: Peri<'static, embassy_rp::peripherals::PIN_17>,
}

/// Ultrasonic Sweep Pins
struct UltrasonicPins {
    /// Servo control pin
    servo: Peri<'static, embassy_rp::peripherals::PIN_18>,
    /// Trigger pin
    trigger: Peri<'static, embassy_rp::peripherals::PIN_14>,
    /// Echo pin
    echo: Peri<'static, embassy_rp::peripherals::PIN_15>,
}

/// Public type for shared I2C bus
pub type I2cBusShared = Mutex<CriticalSectionRawMutex, I2c<'static, I2C0, embassy_rp::i2c::Async>>;

/// Core1 stack (~50 KB).
///
/// Sized to accommodate the IMU task's deep async call stack (DMP firmware
/// load, FIFO loop, nalgebra ops) and the display task's draw-time frames.
/// If stack-overflow symptoms appear the next increment is `Stack<65536>`.
static mut CORE1_STACK: Stack<51200> = Stack::new();

/// Executor for core0 (all non-I2C tasks)
static EXECUTOR0: StaticCell<Executor> = StaticCell::new();

/// Executor for core1 (I2C-dependent tasks: display, IMU, port expander)
static EXECUTOR1: StaticCell<Executor> = StaticCell::new();

/// Firmware entry point
///
/// Uses the canonical Embassy RP multicore pattern:
/// `#[cortex_m_rt::entry]` + two `StaticCell<Executor>` statics +
/// `spawn_core1` for core1 bootstrap.
#[allow(clippy::too_many_lines)]
#[cortex_m_rt::entry]
fn main() -> ! {
    // Configure rp2350 to use the external oscillator and run at its usual 150Mhz
    let mut config = Config::default();
    config.clocks = embassy_rp::clocks::ClockConfig::system_freq(150_000_000)
        .unwrap_or_else(|e| defmt::panic!("Failed to configure system clocks {}", e));
    // get a peripheral handle
    let p = embassy_rp::init(config);

    // --- I2C peripherals: moved into core1 closure so that I2C0_IRQ is
    //     enabled on core1's NVIC when I2c::new_async is called there. ---
    let i2c0 = p.I2C0;
    let pin_scl = p.PIN_13;
    let pin_sda = p.PIN_12;

    // --- Port expander interrupt pin
    let pin_pe_int = p.PIN_20;

    // note: the order of PIO inits is important, PIO0 must be initialized before PIO1 or PIO1 will not work
    // ...not sure why....
    //
    // Initialize PIO0 for ultrasonic sweep
    let Pio {
        common: mut pio0_common,
        sm0: pio0_sm0,
        ..
    } = Pio::new(p.PIO0, Irqs);

    // Initialize PIO1 for various tasks
    let Pio {
        common: mut pio1_common,
        sm0: pio1_sm0,
        sm1: pio1_sm1,
        sm2: pio1_sm2,
        sm3: pio1_sm3,
        ..
    } = Pio::new(p.PIO1, Irqs);

    // Start core1.  It owns the I2C bus and runs the three I2C-dependent tasks.
    // I2C0, PIN_12 (SDA), PIN_13 (SCL), and PIN_20 (port-expander INT) are
    // moved in here; they are not referenced on core0 after this point.
    #[allow(static_mut_refs)]
    spawn_core1(p.CORE1, unsafe { &mut CORE1_STACK }, move || {
        let executor1 = EXECUTOR1.init(Executor::new());
        executor1.run(|spawner| {
            // init_i2c_bus is called from within core1's execution context
            // so that I2c::new_async enables I2C0_IRQ on core1's NVIC.
            let i2c_bus = init_i2c_bus(i2c0, pin_scl, pin_sda);
            init_display(spawner, i2c_bus);
            init_imu_read(spawner, i2c_bus);
            init_port_expander(spawner, i2c_bus, pin_pe_int);
        });
    });

    // Core0 executor: all non-I2C tasks, unchanged from before.
    let executor0 = EXECUTOR0.init(Executor::new());
    executor0.run(move |spawner| {
        // Orchestrator
        init_orchestrate(spawner);

        // Battery monitoring
        init_battery_monitoring(spawner, p.ADC, p.PIN_26);

        // Initialize the rgb indicator led
        init_rgb_led(
            spawner,
            &mut pio1_common,
            pio1_sm0,
            pio1_sm1,
            pio1_sm2,
            RgbLedPins {
                red: p.PIN_28,
                green: p.PIN_22,
                blue: p.PIN_19,
            },
        );

        // Initialize the rotary encoder
        init_rotary_encoder(
            spawner,
            &mut pio1_common,
            pio1_sm3,
            Ec11Pins {
                a: p.PIN_10,
                b: p.PIN_11,
            },
        );

        // initialize the RC Control buttons
        init_rc_buttons(
            spawner,
            RCButtonPins {
                a: p.PIN_4,
                b: p.PIN_5,
                c: p.PIN_6,
                d: p.PIN_8,
            },
        );

        // Initialize motor driver and motor encoders
        init_motor_driver(
            spawner,
            MotorDriverPins {
                lmot_pwm_slice: p.PWM_SLICE0,
                lmot_pwm_a: p.PIN_0,
                lmot_pwm_b: p.PIN_1,
                rmot_pwm_slice: p.PWM_SLICE1,
                rmot_pwm_a: p.PIN_2,
                rmot_pwm_b: p.PIN_3,
                encoder_left_front_slice: p.PWM_SLICE3,
                encoder_left_front_pin: p.PIN_7,
                encoder_left_rear_slice: p.PWM_SLICE2,
                encoder_left_rear_pin: p.PIN_21,
                encoder_right_front_slice: p.PWM_SLICE4,
                encoder_right_front_pin: p.PIN_9,
                encoder_right_rear_slice: p.PWM_SLICE5,
                encoder_right_rear_pin: p.PIN_27,
            },
        );

        init_ir_obstacle_detect(spawner);

        // Initialize the ultrasonic sweep tasks
        init_ultrasonic_sweep(
            spawner,
            &mut pio0_common,
            pio0_sm0,
            UltrasonicPins {
                servo: p.PIN_18,
                trigger: p.PIN_14,
                echo: p.PIN_15,
            },
        );

        // Initialize flash storage task
        init_flash_storage(spawner, p.FLASH, p.DMA_CH0);

        // Initialize testing task for development
        init_testing(spawner);

        // Initialize UI (needs spawner for calibration tasks)
        init_ui(spawner);

        // Initialize autonomous mode controller
        init_autonomous_mode(spawner);

        // Trigger system initialization (loads calibration data + shows UI when ready).
        init_startup(spawner);
    });
}

/// Spawn the startup task that fires the `Initialize` event
#[allow(clippy::unwrap_used)]
fn init_startup(spawner: Spawner) {
    spawner.spawn(task::startup::startup().unwrap());
}

/// Initialize orchestrator task
#[allow(clippy::unwrap_used)]
fn init_orchestrate(spawner: Spawner) {
    spawner.spawn(task::orchestrate::orchestrate().unwrap());
}

/// Initialize battery monitoring task with ADC
#[allow(clippy::unwrap_used)]
fn init_battery_monitoring(
    spawner: Spawner,
    adc: Peri<'static, embassy_rp::peripherals::ADC>,
    adc_pin: Peri<'static, embassy_rp::peripherals::PIN_26>,
) {
    let adc = Adc::new(adc, Irqs, AdcConfig::default());
    let battery_channel = Channel::new_pin(adc_pin, Pull::None);
    spawner.spawn(task::battery_charge_read::battery_charge_read(adc, battery_channel).unwrap());
}

/// Initialize RGB LED indicator with PIO PWM outputs
#[allow(clippy::unwrap_used)]
fn init_rgb_led(
    spawner: Spawner,
    common: &mut embassy_rp::pio::Common<'static, PIO1>,
    sm0: embassy_rp::pio::StateMachine<'static, PIO1, 0>,
    sm1: embassy_rp::pio::StateMachine<'static, PIO1, 1>,
    sm2: embassy_rp::pio::StateMachine<'static, PIO1, 2>,
    pins: RgbLedPins,
) {
    let rgb_program = PioPwmProgram::new(common);
    let pwm_red = PioPwm::new(common, sm0, pins.red, &rgb_program);
    let pwm_green = PioPwm::new(common, sm1, pins.green, &rgb_program);
    let pwm_blue = PioPwm::new(common, sm2, pins.blue, &rgb_program);

    spawner.spawn(task::indicators::rgb_led_indicate::rgb_led_indicate(pwm_red, pwm_green, pwm_blue).unwrap());
}

/// Initialize EC11 rotary encoder (PIO quadrature + button input)
#[allow(clippy::unwrap_used)]
fn init_rotary_encoder(
    spawner: Spawner,
    common: &mut embassy_rp::pio::Common<'static, PIO1>,
    sm3: embassy_rp::pio::StateMachine<'static, PIO1, 3>,
    pins: Ec11Pins,
) {
    let encoder_program = PioEncoderProgram::new(common);
    let encoder = PioEncoder::new(common, sm3, pins.a, pins.b, &encoder_program);

    spawner.spawn(task::control::rotary_encoder::rotary_encoder_turns(encoder).unwrap());
    spawner.spawn(task::control::rotary_encoder::rotary_encoder_button().unwrap());
}

/// Initialize all four RC button inputs
#[allow(clippy::unwrap_used)]
fn init_rc_buttons(spawner: Spawner, pins: RCButtonPins) {
    let btn_a = Input::new(pins.a, Pull::Down);
    spawner.spawn(task::control::rc_control::rc_button_handle(btn_a, system::event::RCButtonId::A).unwrap());

    let btn_b = Input::new(pins.b, Pull::Down);
    spawner.spawn(task::control::rc_control::rc_button_handle(btn_b, system::event::RCButtonId::B).unwrap());

    let btn_c = Input::new(pins.c, Pull::Down);
    spawner.spawn(task::control::rc_control::rc_button_handle(btn_c, system::event::RCButtonId::C).unwrap());

    let btn_d = Input::new(pins.d, Pull::Down);
    spawner.spawn(task::control::rc_control::rc_button_handle(btn_d, system::event::RCButtonId::D).unwrap());
}

/// Initialize motor driver with PWM channels and encoders
/// Direction and standby control are handled via PCA9555 port expander
/// Encoders are passed to the `sensors::encoders` task for sensing
#[allow(clippy::cast_possible_truncation)]
#[allow(clippy::unwrap_used)]
fn init_motor_driver(spawner: Spawner, pins: MotorDriverPins) {
    let desired_freq_hz = 20_000u32;
    let clock_freq_hz = embassy_rp::clocks::clk_sys_freq();
    let divider = ((clock_freq_hz / desired_freq_hz) / 65535 + 1) as u8;
    let period = (clock_freq_hz / (desired_freq_hz * u32::from(divider))) as u16 - 1;
    let mut motor_pwm_config = embassy_rp::pwm::Config::default();
    motor_pwm_config.divider = divider.into();
    motor_pwm_config.top = period;

    // Create PWM slices for 4 motors (2 drivers × 2 motors each)
    // Each PWM slice supports 2 channels (A and B)
    // Left Driver: Channel A = Front motor (GPIO 0), Channel B = Rear motor (GPIO 1)
    // Right Driver: Channel A = Front motor (GPIO 2), Channel B = Rear motor (GPIO 3)

    // Left Driver: GPIO 0 and GPIO 1 on PWM_SLICE0 (channels A and B)
    let pwm_driver_left = Pwm::new_output_ab(
        pins.lmot_pwm_slice,
        pins.lmot_pwm_a,
        pins.lmot_pwm_b,
        motor_pwm_config.clone(),
    );

    // Right Driver: GPIO 2 and GPIO 3 on PWM_SLICE1 (channels A and B)
    let pwm_driver_right = Pwm::new_output_ab(pins.rmot_pwm_slice, pins.rmot_pwm_a, pins.rmot_pwm_b, motor_pwm_config);

    // Configure encoder PWM inputs for pulse counting
    let mut encoder_pwm_config = embassy_rp::pwm::Config::default();
    encoder_pwm_config.divider = 1.into();
    encoder_pwm_config.phase_correct = false;

    // Create encoder inputs (PWM input mode on B channels)
    // Encoder 1: Left Front Motor (GPIO 7, PWM_SLICE3 Channel B)
    let encoder_left_front = Pwm::new_input(
        pins.encoder_left_front_slice,
        pins.encoder_left_front_pin,
        Pull::None,
        InputMode::RisingEdge,
        encoder_pwm_config.clone(),
    );

    // Encoder 2: Left Rear Motor (GPIO 21, PWM_SLICE2 Channel B)
    let encoder_left_rear = Pwm::new_input(
        pins.encoder_left_rear_slice,
        pins.encoder_left_rear_pin,
        Pull::None,
        InputMode::RisingEdge,
        encoder_pwm_config.clone(),
    );

    // Encoder 3: Right Front Motor (GPIO 9, PWM_SLICE4 Channel B)
    let encoder_right_front = Pwm::new_input(
        pins.encoder_right_front_slice,
        pins.encoder_right_front_pin,
        Pull::None,
        InputMode::RisingEdge,
        encoder_pwm_config.clone(),
    );

    // Encoder 4: Right Rear Motor (GPIO 27, PWM_SLICE5 Channel B)
    let encoder_right_rear = Pwm::new_input(
        pins.encoder_right_rear_slice,
        pins.encoder_right_rear_pin,
        Pull::None,
        InputMode::RisingEdge,
        encoder_pwm_config,
    );

    // Spawn motor driver task (handles PWM + coordinates with port expander)
    spawner.spawn(task::motor_driver::motor_driver(pwm_driver_left, pwm_driver_right).unwrap());

    // Spawn encoder read task (handles encoder sensing)
    spawner.spawn(
        task::sensors::encoders::encoder_read(
            encoder_left_front,
            encoder_left_rear,
            encoder_right_front,
            encoder_right_rear,
        )
        .unwrap(),
    );

    // Spawn drive queue executor task (queue-level completion)
    spawner.spawn(task::drive::drive_queue_executor().unwrap());

    // Spawn drive task (high-level drive control)
    spawner.spawn(task::drive::drive().unwrap());
}

/// Initialize IR obstacle detection (signaled by port expander)
#[allow(clippy::unwrap_used)]
fn init_ir_obstacle_detect(spawner: Spawner) {
    spawner.spawn(task::sensors::ir_obstacle::ir_obstacle_detect().unwrap());
}

/// Initialize ultrasonic sensor sweep with servo
#[allow(clippy::unwrap_used)]
fn init_ultrasonic_sweep(
    spawner: Spawner,
    us_common: &mut embassy_rp::pio::Common<'static, PIO0>,
    us_sm0: embassy_rp::pio::StateMachine<'static, PIO0, 0>,
    pins: UltrasonicPins,
) {
    let us_trigger = Output::new(pins.trigger, Level::Low);
    let us_echo = Input::new(pins.echo, Pull::None);

    let us_pwm_program = PioPwmProgram::new(us_common);
    let us_pwm = PioPwm::new(us_common, us_sm0, pins.servo, &us_pwm_program);

    spawner.spawn(task::sensors::ultrasonic::ultrasonic_sweep(us_pwm, us_trigger, us_echo).unwrap());
}

/// Initialize shared I2C bus for display and IMU.
///
/// Must be called from within core1's executor `run` closure so that
/// `I2c::new_async` enables `I2C0_IRQ` on core1's NVIC.
fn init_i2c_bus(
    i2c0: Peri<'static, I2C0>,
    scl: Peri<'static, embassy_rp::peripherals::PIN_13>,
    sda: Peri<'static, embassy_rp::peripherals::PIN_12>,
) -> &'static I2cBusShared {
    static I2C_BUS: StaticCell<I2cBusShared> = StaticCell::new();

    let mut i2c_config = I2cConfig::default();
    i2c_config.frequency = 400_000;

    let i2c = I2c::new_async(i2c0, scl, sda, Irqs, i2c_config);

    I2C_BUS.init(Mutex::new(i2c))
}

/// Initialize display task with I2C bus
#[allow(clippy::unwrap_used)]
fn init_display(spawner: Spawner, i2c_bus: &'static I2cBusShared) {
    spawner.spawn(task::io::display::display(i2c_bus).unwrap());
}

/// Initialize IMU task with I2C bus and interrupt input
#[allow(clippy::unwrap_used)]
fn init_imu_read(spawner: Spawner, i2c_bus: &'static I2cBusShared) {
    spawner.spawn(task::sensors::imu::inertial_measurement_read(i2c_bus).unwrap());
}

/// Initialize port expander task with I2C bus and interrupt pin
#[allow(clippy::unwrap_used)]
fn init_port_expander(
    spawner: Spawner,
    i2c_bus: &'static I2cBusShared,
    int: Peri<'static, embassy_rp::peripherals::PIN_20>,
) {
    let interrupt = embassy_rp::gpio::Input::new(int, Pull::Up);
    spawner.spawn(task::io::port_expander::port_expander(i2c_bus, interrupt).unwrap());
}

/// Initialize flash storage task for persistent calibration data
#[allow(clippy::unwrap_used)]
fn init_flash_storage(
    spawner: Spawner,
    flash_peripheral: Peri<'static, embassy_rp::peripherals::FLASH>,
    dma_ch0: Peri<'static, embassy_rp::peripherals::DMA_CH0>,
) {
    let flash = Flash::<_, Async, { 2048 * 1024 }>::new(flash_peripheral, dma_ch0, Irqs);
    spawner.spawn(task::io::flash_storage::flash_storage(flash).unwrap());
}

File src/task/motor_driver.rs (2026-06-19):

//! Motor Driver Task
//!
//! This module provides a task that controls motor speed and direction through PWM
//! and coordinates with the PCA9555 port expander for direction pin control.
//!
//! # Terminology
//!
//! - **Track**: Left or right side of the robot (each has 2 motors mechanically coupled via belt/chain)
//! - **Motor**: Front or rear position within a track
//! - **Driver**: Physical TB6612FNG motor driver chip (one per track, controls 2 motors)
//!
//! # Architecture
//!
//! The motor driver uses a dual-layer control system:
//! 1. **PWM Control (this module)**: Speed control via PWM duty cycle on GPIO 0-3
//! 2. **Direction Control (`port_expander`)**: Direction pins via PCA9555 I2C expander
//! 3. **Encoder Feedback (this module)**: Pulse counting via PWM input on GPIO 7, 9, 21, 27
//!
//! # Hardware Configuration
//!
//! ## Driver Layout (2 TB6612FNG drivers, 4 motors total)
//!
//! **Left Track Driver (PWM Slice 0, GPIO 0-1):**
//! - Front motor: GPIO 0 (PWM0A)
//! - Rear motor: GPIO 1 (PWM0B)
//!
//! **Right Track Driver (PWM Slice 1, GPIO 2-3):**
//! - Front motor: GPIO 2 (PWM1A)
//! - Rear motor: GPIO 3 (PWM1B)
//!
//! ## Direction Pins (via PCA9555 Port 0)
//! - Left Track, Front Motor: Bits 0-1 (forward/backward)
//! - Left Track, Rear Motor: Bits 2-3 (forward/backward)
//! - Right Track, Front Motor: Bits 4-5 (forward/backward)
//! - Right Track, Rear Motor: Bits 6-7 (forward/backward)
//!
//! ## Standby/Enable Pins (via PCA9555 Port 1)
//! - Left Driver Chip: Bit 4
//! - Right Driver Chip: Bit 5
//!
//! ## Encoder Inputs (PWM Input Mode)
//! - Left Front Motor: GPIO 7 (PWM Slice 3B)
//! - Left Rear Motor: GPIO 21 (PWM Slice 2B)
//! - Right Front Motor: GPIO 9 (PWM Slice 4B)
//! - Right Rear Motor: GPIO 27 (PWM Slice 5B)
//!
//! # Motor Calibration
//!
//! Each motor has an independent calibration factor (0.5 to 1.5) to compensate
//! for manufacturing variations. The calibration is applied as a multiplier
//! to the commanded speed before converting to PWM duty cycle.
//!
//! ## Motor Calibration
//!
//! Motor calibration is now handled by the `drive` task, which coordinates
//! encoder readings from the `encoder_read` task with motor commands to
//! this task. This provides better separation of concerns:
//! - `motor_driver`: Pure actuation (PWM control)
//! - `encoder_read`: Pure sensing (encoder pulse counting)
//! - `drive`: Control logic (calibration procedures)
//!
//! Calibration factors are stored in the `MotorCalibration` struct and can be
//! loaded from flash storage or updated dynamically using the `UpdateCalibration`
//! and `LoadCalibration` commands.
//!
//! # Usage
//!
//! ```rust
//! // Set single motor speed
//! motor_driver::send_motor_command(MotorCommand::SetSpeed {
//!     track: Track::Left,
//!     motor: Motor::Front,
//!     speed: 50,  // 50% forward
//! }).await;
//!
//! // Set all motors at once (atomic operation)
//! motor_driver::send_motor_command(MotorCommand::SetAllMotors {
//!     left_front: 50,
//!     left_rear: 50,
//!     right_front: 50,
//!     right_rear: 50,
//! }).await;
//!
//! // Brake a motor
//! motor_driver::send_motor_command(MotorCommand::Brake {
//!     track: Track::Left,
//!     motor: Motor::Front,
//! }).await;
//!
//! // Load calibration from flash storage
//! motor_driver::send_motor_command(MotorCommand::LoadCalibration(calibration)).await;
//! ```

use defmt::{Format, debug, info, warn};
use embassy_rp::pwm::{Pwm, SetDutyCycle};
use embassy_sync::{blocking_mutex::raw::CriticalSectionRawMutex, channel::Channel};

use crate::{
    system::state::power,
    task::io::port_expander::{self},
};

/// Target motor voltage (we compensate battery voltage down to this)
const TARGET_MOTOR_VOLTAGE: f32 = 6.0;

/// Get current battery voltage from system state (truly non-blocking)
/// Returns None if no voltage reading available yet OR if mutex is busy
fn try_get_battery_voltage() -> Option<f32> {
    power::try_get_battery_voltage()
}

/// Wait for first battery voltage reading from system state
async fn wait_for_battery_voltage() -> f32 {
    loop {
        if let Some(voltage) = try_get_battery_voltage() {
            return voltage;
        }
        // Small delay before checking again
        embassy_time::Timer::after(embassy_time::Duration::from_millis(100)).await;
    }
}

/// Calculate voltage compensation factor
/// This scales duty cycle to maintain 6V output to motors as battery drains
///
/// Examples:
/// - At 8.4V battery: factor = 6.0/8.4 = 0.714 (71.4% duty cycle for 100% speed)
/// - At 7.2V battery: factor = 6.0/7.2 = 0.833 (83.3% duty cycle for 100% speed)
/// - At 6.0V battery: factor = 6.0/6.0 = 1.000 (100% duty cycle for 100% speed)
fn calculate_voltage_compensation(battery_voltage: f32) -> f32 {
    if battery_voltage < TARGET_MOTOR_VOLTAGE {
        // Battery below target - can't compensate, use full range
        warn!(
            "Battery voltage {} below target {}V",
            battery_voltage, TARGET_MOTOR_VOLTAGE
        );
        1.0
    } else {
        TARGET_MOTOR_VOLTAGE / battery_voltage
    }
}

/// Track selection (left or right side of robot)
#[derive(Debug, Clone, Copy, Eq, PartialEq, Format)]
pub enum Track {
    /// Left side of the robot
    Left,
    /// Right side of the robot
    Right,
}

/// Motor position within a track (front or rear)
#[derive(Debug, Clone, Copy, Eq, PartialEq, Format)]
pub enum Motor {
    /// Front motor in the track
    Front,
    /// Rear motor in the track
    Rear,
}

/// Motor direction states
#[derive(Debug, Clone, Copy, Eq, PartialEq, Format)]
pub enum MotorDirection {
    /// Motor moving forward
    Forward,
    /// Motor moving backward
    Backward,
    /// Motor coasting (freewheeling)
    Coast,
    /// Motor braking (short circuit braking)
    Brake,
}
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

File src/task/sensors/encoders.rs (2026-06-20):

//! Encoder reading task for motor speed measurement
//!
//! This module provides a dedicated task for reading encoder pulse counts from all four motors.
//! It separates sensing (encoder reading) from actuation (motor control), following the same
//! architecture pattern as the IMU sensor task.
//!
//! # Architecture
//!
//! The encoder task operates independently from motor control:
//! - **Sensing**: Reads encoder pulse counts at configurable intervals
//! - **Data channel**: Publishes measurements directly to the drive task via `try_send_encoder_measurement`
//! - **Commands**: Accepts control commands (start/stop/reset)
//! - **Power Management**: Can be stopped when not needed
//!
//! # Usage Patterns
//!
//! ## Basic Sampling
//! ```rust
//! // Start reading at 20Hz (50ms interval)
//! encoder_read::send_command(EncoderCommand::Start { interval_ms: 50 }).await;
//!
//! // Stop when done
//! encoder_read::send_command(EncoderCommand::Stop).await;
//! ```
//!
//! ## Delta Tracking (Measuring Motion)
//! ```rust
//! // Reset counters before a maneuver
//! encoder_read::send_command(EncoderCommand::Reset).await;
//!
//! // Perform the maneuver
//! motor_driver::send_command(SetSpeed { speed: 50 }).await;
//! Timer::after(Duration::from_secs(2)).await;
//!
//! // Read the measurement - absolute counts ARE the delta since reset
//! let measurement = wait_for_encoder_event().await;
//! let pulses = measurement.left_front;  // This is the delta!
//! ```
//!
//! ## Auto-Reset for Stop-and-Go
//! ```rust
//! // Enable auto-reset when motors stop
//! encoder_read::send_command(EncoderCommand::AutoResetOnMotorStop(true)).await;
//!
//! // Now encoders automatically reset each time motors stop
//! // Useful for measuring individual drive segments
//! ```
//!
//! # Encoder Hardware
//!
//! - **Type**: Quadrature encoders (using single channel for simplicity)
//! - **Resolution**: 8 pulses per motor revolution
//! - **Gear Ratio**: 120:1 (960 pulses per output shaft revolution)
//! - **Reading Method**: PWM input mode counting rising edges
//! - **Counter Size**: 16-bit (0-65535, wraps around)
//!
//! # Sampling Rate Guidelines
//!
//! - **20-50 Hz** (20-50ms): Good for most control loops
//! - **10 Hz** (100ms): Power-saving mode, suitable for monitoring
//! - **100 Hz** (10ms): High-frequency feedback for precise control
//!
//! Note: Faster sampling increases CPU load but provides better time resolution

use defmt::info;
use embassy_rp::pwm::Pwm;
use embassy_sync::{blocking_mutex::raw::CriticalSectionRawMutex, channel::Channel};
use embassy_time::{Duration, Instant, Timer};

use crate::task::drive;

/// Commands for encoder reading control
#[derive(Debug, Clone, Copy)]
pub enum EncoderCommand {
    /// Start continuous encoder sampling
    ///
    /// # Parameters
    /// - `interval_ms`: Time between samples in milliseconds (e.g., 50 = 20Hz)
    Start {
        /// Sampling interval in milliseconds
        interval_ms: u64,
    },

    /// Stop encoder sampling (power saving)
    Stop,

    /// Reset all encoder counters to zero
    ///
    /// Useful for measuring deltas during maneuvers. After reset, the next
    /// measurement will show how many pulses occurred since the reset.
    Reset,
}

/// Size of the command queue for encoder control
const COMMAND_QUEUE_SIZE: usize = 16;
/// Command channel for encoder control
static ENCODER_COMMAND_CHANNEL: Channel<CriticalSectionRawMutex, EncoderCommand, COMMAND_QUEUE_SIZE> = Channel::new();

/// Send a command to the encoder task
pub async fn send_command(command: EncoderCommand) {
    ENCODER_COMMAND_CHANNEL.sender().send(command).await;
}

/// Receive a command (internal use by encoder task)
async fn receive_command() -> EncoderCommand {
    ENCODER_COMMAND_CHANNEL.receiver().receive().await
}

/// Try to receive a command without blocking (internal use by encoder task)
fn try_receive_command() -> Option<EncoderCommand> {
    ENCODER_COMMAND_CHANNEL.receiver().try_receive().ok()
}

/// Encoder measurement data
///
/// Contains pulse counts from all four motors and a timestamp.
/// Counts are 16-bit values (0-65535) that wrap around on overflow.
#[derive(Debug, Clone, Copy, defmt::Format)]
pub struct EncoderMeasurement {
    /// Left front motor encoder count
    pub left_front: u16,
    /// Left rear motor encoder count
    pub left_rear: u16,
    /// Right front motor encoder count
    pub right_front: u16,
    /// Right rear motor encoder count
    pub right_rear: u16,
    /// Timestamp of measurement in milliseconds since boot
    pub timestamp_ms: u64,
}

/// Encoder channels for all 4 motors
struct EncoderChannels {
    /// Encoder input for left front motor
    left_front: Pwm<'static>,
    /// Encoder input for left rear motor
    left_rear: Pwm<'static>,
    /// Encoder input for right front motor
    right_front: Pwm<'static>,
    /// Encoder input for right rear motor
    right_rear: Pwm<'static>,
}

impl EncoderChannels {
    /// Reset all encoder counters to zero
    fn reset_all(&self) {
        self.left_front.set_counter(0);
        self.left_rear.set_counter(0);
        self.right_front.set_counter(0);
        self.right_rear.set_counter(0);
    }

    /// Read all encoder counts at once
    fn read_all(&self) -> EncoderMeasurement {
        let timestamp_ms = Instant::now().as_millis();
        EncoderMeasurement {
            left_front: self.left_front.counter(),
            left_rear: self.left_rear.counter(),
            right_front: self.right_front.counter(),
            right_rear: self.right_rear.counter(),
            timestamp_ms,
        }
    }
}
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

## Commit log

2024-10-04 Refactor system architecture and add motor control functionality
    • Update resource assignments • Enhance SystemMessage and DriveCommand • Refine SystemState structure • Reorganize module imports • Add tb6612fng motor driver dependency
2024-10-04 Implement distance measurement task and refactor main structure
    • Add distance_measurement task • Remove scheduler task • Update orchestrator task • Modify main to spawn new tasks • Add hcsr04_async feature in Cargo.toml
2024-10-05 Implement battery indicator and refactor distance measurement task
    - Add battery_indicator task
    - Update distance measurement logic
    - Implement event-based system messaging
    - Refactor orchestrator task
    - Update SystemState and related structures
2024-10-09 Update project configuration and refactor system messaging
    • Modify runner command in config.toml • Adjust Cargo.toml profile settings • Remove rust-toolchain.toml file • Refactor system messaging implementation • Update task modules and resource allocation
2024-10-11 Implement battery monitoring and system state management
    - Add battery level monitoring
    - Create system state management
    - Implement orchestrator task
    - Update event handling system
    - Refactor operation mode handling
2024-10-12 Refactor orchestrator and improve event handling in system state
    • Rename distance.rs to distance_measurement.rs • Enhance event handling logic in orchestrator • Implement state change handling • Update SystemState and OperationMode structs • Improve code organiza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
2024-10-12 Rename system_messages to system_events and update related imports
    • Rename system_messages.rs to system_events.rs • Update imports in multiple files • Adjust module declaration in mod.rs • No functional changes, only file renaming
2024-10-12 Refactor tasks and improve system event handling
    • Rename and update task modules
    • Implement battery charge reader
    • Add RGB LED indicator task
    • Enhance orchestrator functionality
    • Improve system event management
2024-10-12 Refactor battery and distance measurement tasks for improved clarity
    - Simplify voltage calculation
    - Remove redundant variable assignment
    - Streamline distance measurement logic
    - Remove unnecessary comments
    - Improve code readability
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2024-11-08 Add autonomous drive, inactivity tracking, and improved motor control
    New autonomous driving system
    Battery-saving inactivity tracking
    Improved PWM motor control logic
    Bug fixes in button handling
    Switch from rand to nanorand crate
    [event.rs, main.rs, mod.rs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]
2024-11-09 Fix autonomous obstacle avoidance reliability and add feedback
    • Improve obstacle avoidance with feedback • Increase minimum distance threshold • Show avoidance logs with defmt • Add state to track avoidance attempts • Fix edge cases in state handling
    [event.rs]
2024-11-15 Improve PWM divider calculation to handle any system clock frequency
    • Calculate minimum safe divider value • Fix hardcoded divider = 16 • Applies to motor and RGB LED PWM • Supports any sys clock frequency • Prevents period overflow
2024-11-16 Add metadata, improve README formatting and clarity
    • Add license and package metadata • Clean up README formatting • Update RC solution description • Improve clarity of explanations • Fix typos
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2024-12-07 Centralize ADC access with mutex to prevent concurrent hardware conflicts
    • Move ADC to global static mutex
    • Remove ADC from BatteryChargeResources
    • Add ADC initialization in main
    [battery_charge_read.rs, main.rs, resources.rs]
2024-12-21 Replace ultrasonic sensor with IR obstacle detection for improved reliability
    • Modified chassis to fit encoder motors
    • Switched to VMA330 IR sensor
    • Removed HC-SR04 ultrasonic code
    • Added IR sensor edge detection logic
    • Updated documentation for new sensor
    [BaseFrame - edit.FCStd, BaseFrame - edit.stl]
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2025-01-01 Schematic & PCB v0.1
    [simple-robot.kicad_pcb, simple-robot.kicad_sch, simple-robot_v01.kicad_pcb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]
2025-01-02 schematic v2
    [simple-robot.kicad_pcb, simple-robot.kicad_sch]
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2025-01-09 update schematic and pcb
    [simple-robot-B_Mask.gbr, simple-robot-B_Paste.gbr, simple-robot-B_Silkscreen.gbr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]
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2025-01-11 update README, clean up the KiCad project a bit, minor refactoring
    [simple-robot_v01.kicad_pcb]
2025-01-11 Refactor RC button tasks into single generic task with ButtonId parameter
    • Consolidate RC button resources into 1 struct • Convert 4 tasks into single generic task • Pass pin and ButtonId as task parameters • Use shorter event module imports
    [main.rs, resources.rs]
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2025-01-11 Improve radar display with text header and dynamic distance/angle readout
    • Switch to FONT_9X15_BOLD for better spacing • Add header area with text display • Use Channel instead of Signal • Add dynamic distance/angle text readout • Clear only sweep area to prevent flicker
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2025-01-12 add servo mount & hc-sr04 mount CAD and print files
    [9g servo mount-BodyPocket001.3mf, 9g servo mount.FCStd, hc-sr04 mount-BodyPocket001.3mf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]
2025-01-16 update 3d models for hc-sr04 mount, update KiCad files, update schematic and PCB
    [9g servo mount.3mf, bom.csv, designators.csv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]
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2025-01-18 Add 3D model files for chassis components and PCB mounting base
    • Added base frame 3MF model
    • Added PCB mount 3MF model
    • Added PCB mount FreeCAD source file
    [BaseFrame - edit.3mf, PCB mounting base.3mf, PCB mounting base.FCStd]
2025-01-23 update some CAD files
    [9g servo mount.3mf, 9g servo mount.FCStd, IR Sensor mount.3mf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]
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2025-01-26 update pcb mount
    [PCB mounting base.3mf, PCB mounting base.FCStd]
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2025-02-02 unifinished save: Refactor motion sensing/correction and button behavior for improved control
    • Update IMU/encoder data collection
    • Refine motion correction logic
    • Improve RC button handling
    • Optimize ultrasonic sweep timing
    • Enhance display updates and feedback
    [event.rs, imu_read.rs, main.rs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]
2025-02-03 Improve radar sweep display with 160° arc and extended 400cm range
    • Adjust servo arc to 160° span • Increase max range to 400cm • Add offset angle for correct arc alignment • Optimize servo movement speed • Set measurement timing and error handling
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2025-02-12 Invert IR sensor output handling and update debounce logic
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2025-02-18 debugging & rewire
    [simple-robot.kicad_sch]
2025-02-20 Update KiCad project files and remove unnecessary autosave and lock files
    [simple-robot.kicad_pcb, simple-robot.kicad_sch]
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2025-12-28 Replace MPU6050 with ICM20948 and add AHRS (#8)
    * Replace MPU6050 with ICM20948 and add AHRS
    * changes after review
    [imu_read.rs]
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2026-01-01 Reprint (#10)
    * Update BaseFrame and add track pin print files
    * Add 3D printed chassis and attribution
    Include FreeCAD sources, Bambu Studio print projects (.3mf), and
    print-ready .stl components for the robot chassis. Add original
    Proto-Tank files under misc/chassis/proto-tank plus ATTRIBUTION.md and
    LICENSE.txt to satisfy CC BY 4.0 requirements
    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
    [Accessory_BaseTrayL298N.stl, Accessory_BatteryCase.stl, Accessory_BatteryCover.stl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]
2026-02-08 Dev into main (#18)
    * Port expander and pin redistribution (#11)
    * isolate few components to start with, comment the rest. Introduce new
    motor driver without tb6612fng driver, also use a new port expander for
    this.
    * Add flash-backed calibration storage
    Add sequential-storage and embedded-storage-async dependencies and use
    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
    [Riser.FCStd, bom.csv, designators.csv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]
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2026-02-16 Introduce a new system to register and execute drive actions until their (#22)
    * Introduce a new system to register and execute drive actions until their
    completion. For now this only really is required for exact Rotation but
    eventuall will at least be useful for dedicated distance driving. Select
    over a drive command and a drive interrupt to allow emergecy commands
    like stopping dead. Drive Commands can be enqueued. Completion telemetry
    for now only has implementation for rotation completion data, more can
    be added later.
    * Stop motion data collection on drive end
    Emit StartStopMotionDataCollection(false) when a drive or rotation
    completes or fails to ensure data collection is stopped bef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
    [encoders.rs, event.rs, imu.rs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]
2026-02-17 Straight and curved driving with feedback (#23)
    * straight and curved drive commands with feedback
    Building on given drive command feedback system introducing straight and
    curved with feedback, simple revolution counts for now.
    * Remove legacy auto-calibration and tidy drive code
    Remove the legacy auto-start calibration task from the testing
    module. Clean up unused #[allow(dead_code)] attributes in the
    distance drive code and add a TODO doc noting upcoming curve-control
    changes to a radius/arc-length model.
    * Use radius/arc-length curve model
    Replace Curved revolutions model with DriveDistanceKind::CurveArc
    (radius_cm, arc_length_cm, direction). Rename DriveTrackSide to
    TurnDirection. C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
    [distance.rs, drift.rs, lifecycle.rs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]
2026-02-21 Drive module tidying (#24)
    * Remove drive/control module and rewire references
    Delete drive/control submodule files and update imports/usages.
    Repointed drive::control::RotationState references to
    drive::rotation::RotationState,
    adjusted docs and types comments, and updated a test to use
    DriveAction::Coast.
    * Refactor drive sensor infrastructure and drift
    Reorganise drive module layout: split sensor feedback into
    sensors::data (data plane) and sensors::control (control plane),
    replace feedback.rs and lifecycle.rs with the new modules, and add a
    sensors mod. Extract pure drift calculations into drift::math (remove
    compensation.rs) and rename/reshape drift module. Add handlers.rs for
    DriveL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
    [control.rs, data.rs, distance.rs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]
2026-02-22 rp235x E9 erratum hitting: rotary encoder should be reffed to common GND (#25)
    * rp235x E9 erratum hitting: rotary encoder should be reffed to common GND
    instead of 3V3
    Pulldowns on RP235x only work on after stepping A4, all my boards are
    stepping A2. So thereference for the encoder should not be 3V3 because
    that we will need to pull down and that will latch on the RP.
    Workaround is to add pulldowns which i will do for now but a proper
    workaround is to change the pcb and schematic to have a common GND
    instead of common 3V3 on the encoder and use pullup.
    This commit changes schematic and pcb.
    * Update PCB image link in README
    * Remove old simple-robot KiCad schematic image
    * Simplify RE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
    [simple-robot-B_Mask.gbr, simple-robot-B_Paste.gbr, simple-robot-B_Silkscreen.gbr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]
2026-02-22 Replace PCB mounting base with PCB mount (#26)
    [PCB mount.3mf, PCB mount.FCStd, PCB mounting base.3mf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]
2026-02-22 Add battery holder design files (#27)
    [battery holder.FCStd, battey holder bar.3mf, battey holder case.3mf]
2026-02-28 Update battery holder CAD and 3MF files (#28)
    [battery holder.FCStd, battey holder bar.3mf, battey holder case.3mf]
2026-02-28 Fix rgb led pwm (#30)
    * Remove 0.4 green scaling in LED blend
    * Use PIO0 for ultrasonic sweep
    Swap PIO assignments so PIO0 handles the ultrasonic sweep and PIO1
    handles other PIO-based tasks. Rename local PIO variables
    (pio0_*/pio1_*)
    and remove the now-obsolete UltrasonicSweepPins struct. Update
    ultrasonic
    servo pin mapping.
    [main.rs]
2026-02-28 Autonomous simple mode (#29)
    * Add coast-and-avoid autonomous mode and UI
    Introduce autonomous_mode::coast_obstacle_avoid with
    start/stop/is_active
    API and long-lived embassy task; spawn it from main and remove the
    legacy autonomous_drive module.
    When coast mode is active the obstacle handler issues EmergencyBrake
    interrupts to unblock drive commands. Add Drive Mode submenu and UI
    state
    entries. Adjust battery voltage calibration and LED PWM mapping.
    * Handle DriveModeMenu in render_current_ui
    * fmt
    * clippy was sad
    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
    [battery_charge_read.rs, main.rs, mod.rs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]
2026-03-01 Testing tweaks (#31)
    * enter into menu on boot
    * debounce encoder turning
    * wrong register for button press on port expander
    * style of menu selection improved and more intuitive turning direction
    for te encoder.
    * calibration ui flow 1
    * add toolchain config
    * some lints
    * add imu test mode and improve menu navigation by adding back option in
    some places
    * update some things from review, also removed a hacky lazy encoder
    turning inversion.
    * Fix IMU calibration steps and related fixes
    Update calibration step labels to 10 steps and adjust logging. Use
    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
    [event.rs, imu.rs, main.rs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]
2026-03-01 Replace separate sensor mounts with front array (#32)
    Remove 9g servo and IR sensor mount files and add a combined front
    sensor array (3mf and FCStd). Update ATTRIBUTION.md to describe the
    new sensor array and the added battery pack enclosure.
    [9g servo mount.3mf, 9g servo mount.FCStd, IR Sensor mount.3mf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]
2026-03-06 Ir us testmode (#33)
    * new testmode for ultrasonic and ir sensors
    * misassigned trig and echo pins fixed
    * obstacle detection should blink the indicator
    * Update schematic and pcb: IR_OBST net needs to be pulled low
    * add ultrasonic sweep test mode
    * The US measurements must not assume maximum distance if timing or
    erroring out, in that case we simply have no data which represents cases
    better, where we measure >maxdistance
    * break test mode into more files, no blanket spawning of all test modes
    * do not use us measurement >200cm
    * dislay ownership conflict
    * guard against running two testmode tasks simultaneously
    * do not leak us values into later uses
    * indicate obstacve and no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
    [simple-robot.kicad_pcb, simple-robot.kicad_sch]
2026-03-07 Motor test (#34)
    * test mode for all motors
    * prevent unexpected screen cearing
    * add ultrasonic into the obstacle detection
    * WIP make coast & avoid work
    * extract calibration from system state
    * split off power state from global state
    * extract perception fields out of system state
    * extract motion data from system state, also move track speeds to atomics
    * extract UI from state, remove lingering global state references
    * remove unused things, cleaning up
    * fix diagnostix
    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
    [basic_motor.rs, calibration.rs, data.rs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]
2026-03-08 Rework imu calibration (#35)
    * reworking imu calibration as three separate actions and make mag
    calibration more usable
    * normalize mag and accel
    * copilot review
    * add 6axis fusion testmode. attempt to get magnetometer calibrated, so
    far with limited success. set the entire system to default to 6axis imu
    operations as a stopgap solution.
    * default mode for ahrs fusion
    * Add RAII guard for IMU readings during calibration
    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
    [control.rs, data.rs, imu.rs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]
2026-03-16 readme and drive system updates (#36)
    * Always issue emergency brake in coast mode
    Send EmergencyBrake whenever a combined obstacle is present, not only
    when the obstacle state changes. Also remove ultrasonic-distance gating
    and its constant/import from the coast obstacle avoid task.
    * Use single completion channel for drive commands
    Replace fixed pool of per-command completion handles with a single
    one-slot channel and hardened complete_drive_command API. Commands now
    carry a completion_requested flag instead of an attached sender. Update
    drive handlers, types, and docs to follow the single-producer
    completion semantics and simplify interrupt/epoch cancellation logic.
    * Add drive queue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
    [brake_coast.rs, main.rs, mod.rs]
2026-03-31 Basic drive test (#37)
    * turns still overshoot and curves still start turning too late, but
    better than before
    * add stillness detection to trim gyro
    * ultrasonic sweep now also displays the sweep line when timing out at the
    given measurement angle.
    * introduce idle, brake and coast as drive intents, so that we can enqueue
    these into the overall drive queue system
    * use new queueing options in test sequence, slight refactor
    * review comments
    [control.rs, data.rs, distance.rs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]
2026-05-16 fix broken nets on pcb (#38)
    swapping of trigger and echo pins was incomplete on pcb nets
    update to recent KiCad version
    [simple-robot.kicad_pcb]
2026-05-16 Update versions (#39)
    * update to 1.95.0
    also ci should respect the toolchain version and we do not need clippy
    with and without features because we have no features
    * clippy: use more readable unit
    * Install pinned Rust toolchain from file
    * try if cargo will install toolchain
    * update embassy dependencies
    Had tio change how things spawn, and in one instance of the autonomous
    mode that led to needing to ge the spawnnig out of main fn.
    autonomous_mode now follows the pattern of testmode re spawning tasks.
    * fix: address PR review comments
    - coast_obstacle_avoid_task: remove outer loop + START_SIGNAL so the
    task exits after each run, matching the spawn-on-demand pattern used
    by te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
    [basic_motor.rs, main.rs, mod.rs]
2026-05-16 Migrate IMU to ICM20948 DMP and remove AHRS (#40)
    * Migrate IMU to ICM20948 DMP and remove AHRS
    * Delete imu-dmp-migration-plan.md
    * Bump version, handle legacy IMU key, fix IMU axes
    Keep legacy IMU key (1) so the flash scanner can skip pre-DMP
    120-byte records without aborting scans. Restore current ImuCalibration
    to key 3 and document both schemas. Swap DMP roll/pitch mapping to
    match the robot body frame (sensor axes differ)
    * Rename AhrsFusionMode to DmpFusionMode
    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
    [calibration.rs, control.rs, data.rs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]
2026-06-06 Bump deps, lower log level, handle ultrasonic NaN (#41)
    Update rust toolchain to 1.96.0 and bump moving_median to 0.4.0.
    Set DEFMT_LOG to info and change battery log to use debug.
    Make ultrasonic median filter propagate add_value errors and map None
    median to UltrasonicReading::Error.
    [ultrasonic.rs]
2026-06-09 Revisit drive control (#42)
    * refine drive control:
    implement better compensation on stationary turns and correct straight
    motion only by imu. also split the test modes into distint turn,
    straight, arc.
    * introduce drive queue with or wothout aborting flag
    allows using the queue to abort on failure or skip to next step. A step
    marked abortive on failure ends the queue.
    * noisy logs
    * Remove host-calibrated accelerometer support
    Drop LATEST_CALIBRATED_ACCEL and get_latest_calibrated_accel.
    Stop requesting host_calibrated_accel from the DMP and update
    testmode to display raw accelerometer values instead.
    * Refactor rotation math and update drive calibration
    Replace accumulated-angle trac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
    [calibration.rs, control.rs, distance.rs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]
2026-06-10 Fix coast and avoid (#43)
    * Fix queue status handling for concurrent cancellations and failures
    * Increase obstacle detection threshold to 13 cm
    * Reduce obstacle detection threshold and improve re-avoidance logic
    Increase ultrasonic obstacle threshold from 13 cm to 15 cm. Refactor
    avoidance maneuver to loop until path is clear, using turn-only
    re-attempts with opposite direction and fresh sensor checks after each
    turn.
    * Move clippy allow and rng init, remove dead assignment
    * Remove unnecessary clippy suppression
    [ultrasonic.rs]
2026-06-18 Refactor and deepen drive module (#45)
    * Deepen perception module with atomic obstacle flags and private mutex
    Migrate obstacle detection state to lock-free atomic flags, keeping
    ultrasonic readings behind a private mutex exposed via accessors.
    Consolidate duplicated reset/clear logic into dedicated API methods.
    - Add `AtomicBool` flags for IR, ultrasonic, and combined detection
    - Introduce `ChangeDetected` enum for setter return values
    - Replace direct `PERCEPTION_STATE` access across all consumers
    - Remove local atomics from `obstacle.rs` and delegate to perception
    - Eliminate inline mutex locks in UI, test modes, and behavior tasks
    * add refactoring skill
    * review commentd
    * Refactor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
    [brake_coast.rs, calibration.rs, dispatch.rs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]
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2026-06-19 Consolidate IMU sensor state into a single struct (#47)
    * Consolidate IMU sensor state into a single struct
    Replace six separate `LATEST_*` statics and their individual accessors
    with a
    single `LATEST_READINGS` mutex containing a new `ImuReadings` struct.
    Expose
    all fields through a unified `get_latest_readings()` async function,
    reducing
    lock contention and simplifying the public API. Update the two test-mode
    tasks
    to use the consolidated interface.
    * Clear magnetometer fields when switching to Axis6 fusion mode
    * Derive Debug, Clone, Copy for ImuReadings and simplify getter
    * Update DMP mode switch failure handling to restore previous config
    When a DMP mode switch fails, the previous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
    [imu.rs]
2026-06-20 Leaky UI and event seams (#49)
    * Refactor sensor data flow to point-to-point channels
    Replace the event-based sensor routing with direct channels between
    sensor tasks and the drive subsystem. Remove the now-unnecessary
    sensor event variants and the motion/sensor_events behavior modules.
    Consolidate IMU start/stop calls to direct function invocations instead
    of raising events through the orchestrator. Update ultrasonic sweep
    handling to write perception state directly from the sensor task.
    * Add debug-level logging for ultrasonic sensor events
    * Optimize UI refresh by caching perception state
    * Increase event channel capacity to 64, update sensor docs
    Clarify UI controller architecture: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
    [control.rs, data.rs, dispatch.rs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]
2026-06-20 Stabilze obstacle detection (#50)
    * Update resistor value from 10k to 3K3 and bump KiCad project revision to
    6
    * Add coast-avoid detection test and raise obstacle threshold to 20 cm
    - Add CoastAvoidDetection test mode to verify
    IR→perception→EmergencyBrake chain
    - Raise ultrasonic obstacle threshold from 15 cm to 20 cm for better
    noise margin
    - Increase IR signal channel capacity from 4 to 16 to prevent overflow
    - Fix obstacle indicator update to always run regardless of change
    detection
    - Skip forward drive phase when obstacle already present at startup
    * Bump version and update test doc for motor-noise replication
    Expand the stationary-test docstring to clarify that motors sh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
    [simple-robot.kicad_pcb, simple-robot.kicad_sch]
2026-07-05 Straight drive path (#55)
    * Add domain modeling, grilling, handoff, and documentation skills
    * Add autonomous attempt-straight-line mode with gap analysis
    Add a new autonomous drive mode that sweeps the ultrasonic sensor across
    0-160°, identifies clear gaps, and drives through the best gap toward a
    user-defined target distance while correcting accumulated drift.
    Key components:
    - Attempt-straight-line state machine with sweeping, deciding, and
    driving phases
    - Gap analysis algorithm that finds contiguous clear arcs, filters by
    lateral width and heading limits, and selects the best gap by
    proximity to the correction angle
    - New ultrasonic sweep completion event and buffered sweep me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
    [attempt_straight_line.rs, event.rs, imu.rs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]
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
